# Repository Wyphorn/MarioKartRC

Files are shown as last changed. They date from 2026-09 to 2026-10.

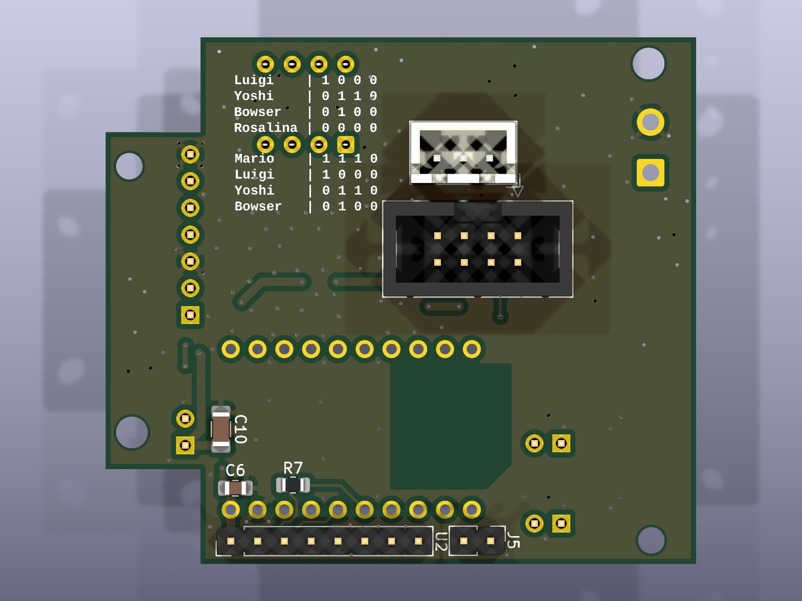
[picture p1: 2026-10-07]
docs/images/kart/3d_bottom.jpg

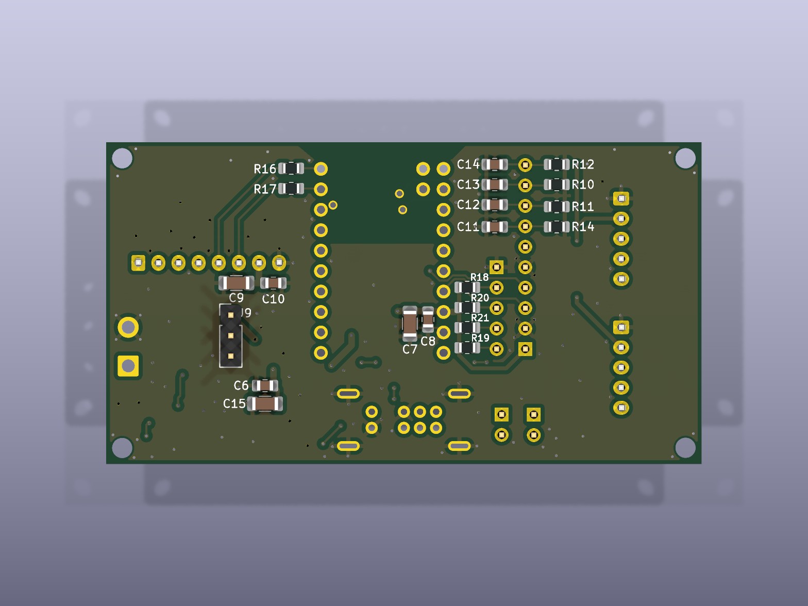
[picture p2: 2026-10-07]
docs/images/controller/3d_bottom.jpg

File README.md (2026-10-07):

# Mario Kart RC

Mario-Kart-inspiriertes RC-Rennsystem für 8 Fahrzeuge im Außeneinsatz. Die Autos fahren mit ~30 km/h; Items, Kollisionen und Rundenzählung werden automatisch erkannt.

Das Projekt ist auf Nachbau ausgelegt: Alle Bauteile haben eine feste Bestellnummer eines echten Herstellers mit öffentlichem Datenblatt und sind handlötbar (SOT-23, SOT-223, SMA, THT – kein QFN).

---

## Repo-Struktur

| Ordner | Inhalt |
|---|---|
| `fb-firmware/` | Fernbedienung – ESP32-C6-SuperMini, PlatformIO |
| `car-firmware/` | Fahrzeug – ESP32-C6 Mini, PlatformIO |
| `shared/` | Gemeinsamer Code: `mk_protocol.h` (Pakete FB ↔ Auto ↔ Basis), `mk_clock_guard.h` (Workaround für den C6-Uhrenfehler) |
| `kicad/projects/` | KiCad-Projekte je Platine: `kart` (Fahrzeug-Board), `controller` (Fernbedienung), `buttons` (Tasterplatine FB), `switch` (Schalter-Platinchen Kart), jeweils mit Gerber als ZIP |
| `kicad/libs/` | Eigene Symbole und Footprints (`zzzz_Own`, `RF_Module_Own`), von allen Projekten über ihre lokalen Bibliothekstabellen eingebunden |
| `kicad/archive/` | Alte Stände: FB-V1-Layout, erster FB-Schaltplan (D1 Mini, Mai 2026) |
| `docs/` | Weitere Dokumentation, u.a. `base-station.md` |

---

## Gesamtarchitektur

| Bereich | Technologie |
|---|---|
| Drahtlos | ESP-NOW |
| Kabelgebunden | CAN-Bus (STM32F103 + TJA1050) |
| Basisstation | Raspberry Pi 5 + USB-CAN-Adapter |
| Fahrzeugbasis | Carrera 2013 RC-Autos (umgebaut) |
| Fahrzeug-MCU | ESP32-C6 Mini |
| Fernbedienung | ESP32-C6-SuperMini (gleicher Chip wie im Auto) |

**Faustregel:** kabelgebunden = CAN, drahtlos = ESP-NOW.

---

## Betriebs-Modi

**Direct Mode** – Die Fernbedienung (FB) steuert ihr Auto direkt. Keine Basisstation nötig, ideal zum Einzelfahren und Testen.

**Game Mode** – Die FB spricht mit der Basisstation. Diese übernimmt die Spiellogik (Items, Punkte, Kollisionen, Rundenzählung) und leitet die Fahrbefehle ans Auto weiter.

Gewählt wird der Modus mit dem Schiebeschalter der FB: Mitte = Aus, Links = Game, Rechts = Direct.

---

## Kommunikationsprotokoll (`shared/mk_protocol.h`)

Alle ESP-NOW-Pakete beginnen mit einem `uint8_t type` als Unterscheidungsmerkmal.

| Struct | Richtung | Frequenz |
|---|---|---|
| `MK_ControlInput` | FB → Auto (Direct) / FB → Basis (Game) | ~50 Hz |
| `MK_ConfigPacket` | FB → Auto / FB → Basis → Auto | nur bei Änderung |
| `MK_GameFeedback` | Auto → FB (Direct) / Basis → FB (Game) | 5 Hz |
| `MK_Beacon` | FB/Auto → Broadcast | beim Pairing |
| `MK_Assign` | Basis → FB/Auto (Unicast) | beim Pairing |
| `MK_ChannelSwitch` | Basis/FB → Auto | Kanalwechsel / Rennende |
| `MK_Mapping` | Basis → FB/Auto (Unicast) | vor Rennstart |
| `MK_IrConfig` | Basis → Auto (Unicast) | nach Assign (nur Game Mode) |

- **`MK_ControlInput`** – `throttle` und `steering` (–100..100), `buttons` (Bitmaske Gelb/Grün/Blau/Rot), `maxSpeed` (1–10)
- **`MK_ConfigPacket`** – Servo-Trim –10..10; `save = 1` speichert im Auto-EEPROM, `save = 0` ist eine Live-Vorschau
- **`MK_GameFeedback`** – Position, Runde, Item, Rumble, Akkustand des Autos (0–5) und sein aktueller Servo-Trim
- **`MK_Beacon`** – enthält beim Auto die Charakter-ID (1–8)

### Pairing und Wiederverbinden (Direct Mode)

1. Erstes Pairing auf dem Setup-Kanal 1: Das Auto sendet Beacons, die FB antwortet mit `MK_Assign` und schickt es per `MK_ChannelSwitch` auf einen zufälligen Betriebskanal (4, 6, 9 oder 11).
2. Beide speichern Kanal und Gegenstelle im EEPROM.
3. **Wiederverbinden ist FB-gesteuert:** Nach einem Neustart oder Funkabriss meldet sich die FB mit ihrer echten MAC auf dem gespeicherten Kanal beim gespeicherten Auto und sendet einfach Steuerpakete. Das Feedback des Autos bestätigt die Verbindung – kein Beacon, kein erneutes Assign.
4. Rückfall auf Kanal 1 erst, wenn die Gegenstelle wirklich weg ist: Auto nach 30 s Funkstille (5 s direkt nach dem Einschalten), FB nach 30 s (15 s nach dem Einschalten). Kanal 1 wird bewusst vermieden, weil dort die erste FB gewinnt und die Zuordnung FB ↔ Auto wechseln könnte.

---

## Fernbedienung

### Hardware

| Komponente | Details |
|---|---|
| MCU | ESP32-C6-SuperMini (MakerGO) |
| Joysticks | 2× PS2-Analog-Stick, direkt an 3.3V (kein Spannungsteiler) |
| ADC | ADS1115 als Breakout-Modul, I2C 0x48 (ADDR → GND) |
| Display | 1.9" IPS 170×320, ST7789, SPI |
| Buttons | 4× Taster (SNES-Raute) + 2× Stick-Taster (verdrahtet, ohne Funktion) |
| Status-LED | WS2812B, 330 Ω Serienwiderstand |
| Rumble | 2× ERM-Vibrationsmotor 28×12 mm, parallel an Zellspannung |
| Rumble-Treiber | 1× MMBT2222A + 1 kΩ Basis, 1× SS14 Freilaufdiode |
| Akku | 1× 18650, ungeschützt – zum Laden herausnehmen (externes Ladegerät) |
| Verpolschutz | P-MOSFET DMG2301L-7 (Ersatz: DMG2301LK-7), direkt hinter dem Akku |
| Spannungsregler | LDO MCP1826T-3302E/DC, fest 3.3V, 1 A |
| Power/Modus | Schiebeschalter 2P3T: Pol A schaltet SHDN des LDO, Pol B den Modus-Pin |
| Akku-Messung | Teiler 100k/100k + 100 nF an GPIO0 |
| Puffer | 220 µF Elko an der Akkuschiene (Rumble-Anlaufstrom) |

Alle Verbraucher außer dem Rumble laufen an einer einzigen 3.3V-Schiene.

> **Hinweis für Nachbauer:** Auf FB-Board V1 ist die Freilaufdiode D2 im Footprint verdreht. Den Kathodenring entgegen dem Siebdruck auf Pad 2 (+BATT) setzen – das ist die Seite mit Durchgang zu Pin 1 von J6/J7.

### Pinbelegung ESP32-C6-SuperMini

| GPIO | Funktion |
|---|---|
| GPIO0 | ADC – Akku-Messung |
| GPIO1 | Modus-Pin (Game = GND, Direct = 3.3V) |
| GPIO2 | Button Rot |
| GPIO3 | Button Blau |
| GPIO4 | Button Grün |
| GPIO5 | Display MOSI |
| GPIO6 | WS2812B DATA |
| GPIO7 | Display SCK |
| GPIO14 | Display Backlight (PWM) |
| GPIO15 | Display CS |
| GPIO17 | Rumble PWM |
| GPIO18 | Display DC |
| GPIO19 | I2C SDA (ADS1115) |
| GPIO20 | I2C SCL (ADS1115) |
| GPIO21 / 22 | Stick-Taster R / L (inneres Pad, reserviert) |
| GPIO23 | Button Gelb (inneres Pad, einzelner Draht) |

Tabu: GPIO8/9 (Strapping, Onboard-LED/BOOT), GPIO12/13 (USB zum Flashen und für den Serial-Monitor), GPIO16 (UART0 TX, wird vom Boot-ROM getrieben).

ADS1115-Kanäle: A0 = Links X, A1 = Links Y, A2 = Rechts Y, A3 = Rechts X (A2/A3 bewusst getauscht, damit sich die Leitungen nicht kreuzen).

### Tastenbelegung

```
        [Blau]
   [Grün]      [Rot]
        [Gelb]
```

| Taste | Im Menü | Beim Fahren |
|---|---|---|
| Grün | Bestätigen | – |
| Rot | Zurück / Abbrechen | Licht am Auto an/aus |
| Blau | – | Charakter-Sound |
| Gelb | – | – (frei) |
| Grün + Blau 3 s | – | Menü öffnen |
| Rot 10 s halten | – | Einstellungen zurücksetzen (Countdown ab 5 s) |
| Rot beim Einschalten | Einstellungen zurücksetzen | |

Standardbelegung der Sticks: links hoch/runter = Gas, rechts links/rechts = Lenkung (im Menü tauschbar).

### Status-LED

| Farbe | Bedeutung |
|---|---|
| Orange blinkend | sucht Auto bzw. Basis |
| Grün | verbunden |
| Orange | Akku unter 33 % |
| Rot blinkend | Akku unter 16 % |
| Pink | Menü offen |
| Gelb pulsierend / solid | Kalibrierung startet / läuft |

### Einstellungsmenü

| Menüpunkt | Gespeichert |
|---|---|
| Offset-Kalibrierung (Nullpunkt der Sticks) | FB |
| Min/Max-Kalibrierung (8 geführte Schritte) | FB |
| Servo-Trim (±10, Räder bewegen sich live mit, Grün speichert, Rot verwirft) | Auto |
| Max. Speed (1–10) | – |
| Sprache (DE/EN) | FB |
| Rumble an/aus | – |
| Joysticks tauschen | – |
| Debug (Achsen, Buttons, Spannung, Kanal, MAC) | – |
| Reset | – |

Vor der ersten Fahrt **Offset-Kalibrierung** machen – sonst liegt der Nullpunkt der Sticks daneben und das Auto kriecht los.

### Akku

- 0 % = 3.4V, 100 % = 4.2V. Unter ~3.35V fällt der LDO aus der Regelung und die Joystick-Werte wandern – deshalb gilt die Zelle schon bei 3.4V als leer.
- **Tiefentladeschutz:** Liegt die Zelle 30 s unter 3.3V, zeigt die FB „Akku leer – bitte ausschalten“ und geht in Deep Sleep. Nur Aus- und Einschalten holt sie zurück. Ein Restverbrauch von wenigen mA bleibt; bei längerer Lagerung die Zelle herausnehmen.
- Nach 60 s ohne Eingabe wird das Display gedimmt.

---

## Fahrzeug

### Hardware

| Komponente | Details |
|---|---|
| MCU | ESP32-C6 Mini |
| Motortreiber | BTS7960 H-Brücke (IBT-2), 43 A Peak |
| Antrieb | 380er Bürstenmotor, 7.4V, Stallstrom ~8 A |
| Lenkservo | Multiplex MS-12022 MG DIGI, PWM 1050–1950 µs (mechanischer Puffer) |
| Audio | DFPlayer Mini (UART) – Sounds aus einem Ordner pro Charakter |
| IMU | LSM6DS3, I2C 0x6A – Kollisionserkennung |
| LEDs | WS2812B-Kette: Status-LED + 8er-Kreis im Charakterkopf |
| Beleuchtung | Front weiß + Heck rot, Rückfahrlicht weiß |
| IR-Sender | 3× IR-LED 940 nm nach unten (Mitte, ±8 cm) – Typ noch offen |
| Charakter-ID | 4-fach DIP-Schalter + Widerstandsleiter an einem ADC-Pin |
| Akku | 2× 18650 in Serie (2S), ungeschützt – zum Laden herausnehmen |
| Stromversorgung | 7.4V direkt an den BTS7960, 5V über Buck AP63205WU (C6, DFPlayer, LEDs, Servo) |
| Akku-Messung | Teiler 100k/47k an GPIO4 |

### Pinbelegung ESP32-C6 Mini

| GPIO | Funktion |
|---|---|
| GPIO0 | I2C SCL (LSM6DS3) |
| GPIO1 | I2C SDA (LSM6DS3) |
| GPIO2 | ADC – Charakter-ID |
| GPIO3 | IR-LED (über MMBT2222) |
| GPIO4 | ADC – Akku-Messung |
| GPIO5 | BTS7960 RPWM (10k Pulldown) |
| GPIO6 | BTS7960 LPWM (10k Pulldown) |
| GPIO7 | Servo PWM |
| GPIO14 | Rückfahrlicht |
| GPIO15 | Front- + Rücklicht |
| GPIO18 | UART1 TX → DFPlayer RX |
| GPIO19 | UART1 RX ← DFPlayer TX |
| GPIO20 | WS2812B DATA |

BTS7960 R_EN/L_EN fest an 5V. GPIO8/9 bleiben frei (Strapping: dürfen beim Reset nicht auf LOW gezogen werden).

### Charakter-Identifikation (DIP-Schalter)

10 kΩ nach 3.3V, dazu vier Widerstände (4.7k / 10k / 20k / 51k), je per DIP-Schalter nach GND. Der kleinste Abstand zwischen zwei Charakteren beträgt 254 mV.

| Charakter | DIP [4.7k 10k 20k 51k] | Spannung | SD-Ordner |
|---|---|---|---|
| Mario | 1110 | 0.713V | 01 |
| Luigi | 1000 | 1.055V | 02 |
| Yoshi | 0110 | 1.320V | 03 |
| Bowser | 0100 | 1.650V | 04 |
| DK | 0011 | 1.946V | 05 |
| Peach | 0010 | 2.200V | 06 |
| Toad | 0001 | 2.759V | 07 |
| Rosalina | 0000 | 3.300V | 08 |

Wird der DIP-Schalter umgestellt, während das Auto nicht verbunden ist, spielt es zur Kontrolle den Erkennungssound des neuen Charakters.

### SD-Karte des DFPlayers

```
/01/  001.mp3, 002.mp3, …   ← Mario
/02/  …                     ← Luigi
…
/08/  …                     ← Rosalina
/09/  …                     ← Spiel-Sounds (Stern, Banane, …)
```

Welche Tracks fröhlich bzw. traurig sind, steht in den Arrays `kJoy_*` / `kSad_*` am Anfang von `car-firmware/src/main.cpp`.

### LEDs

| Index | Funktion |
|---|---|
| 0 | Status-LED |
| 1–8 | Charakter-Kreis (Regenbogen) |

| Status-LED | Bedeutung |
|---|---|
| Orange blinkend | sucht / Verbindung unterbrochen |
| Grün | verbunden |
| Gelb | Akku unter 3.3V/Zelle |
| Rot blinkend | Akku unter 3.2V/Zelle – Abschaltung steht bevor |

### Akku

**Tiefentladeschutz:** Liegt der Akku 30 s unter 6.4V (3.2V/Zelle), stoppt das Auto, spielt einen traurigen Sound und geht in Deep Sleep. Jede Messung zählt, auch unter Last; eine erholte Messung beim Gaswegnehmen setzt den Zähler zurück. So löst es im Rennen erst aus, wenn der Akku wirklich leer ist.

### Kollisionserkennung

LSM6DS3 im ±16g-Bereich. Bei einem Stoß über der Schwelle vibriert die gekoppelte FB 2 s lang, danach 3 s Pause. Die Schwelle steht zum Testen auf 1.5g und soll nach dem Fahrtest wieder auf ~6g.

---

## Firmware bauen und flashen

```bash
cd fb-firmware      # bzw. car-firmware
pio run -t upload
pio device monitor
```

`upload_port`/`monitor_port` in `platformio.ini` sind auf die Seriennummern der eigenen Boards festgelegt – für andere Boards anpassen oder entfernen. Geflasht wird über den eingebauten USB-Port des C6 (USB-Serial/JTAG).

Beide Firmwares nutzen eine OTA-taugliche Partitionstabelle (`default.csv`). Sie lässt sich nur per USB ändern, deshalb ist sie ab dem ersten Flash gesetzt.

### ESP32-C6 rev v0.2: Uhr springt zurück

Beim ESP32-C6 in Revision v0.2 fallen im Zeitgeber gelegentlich einzelne Bits aus, sobald Funk und ein I2C-Master gleichzeitig laufen – `millis()` springt dann um Sekunden bis Minuten zurück ([esp-idf #19036](https://github.com/espressif/esp-idf/issues/19036)). Die Firmware umgeht das mit `shared/mk_clock_guard.h`:

- `nowMs()` zählt über den FreeRTOS-Tick, der auf einem nicht betroffenen Zähler läuft. Im eigenen Code **immer `nowMs()` statt `millis()` verwenden.**
- Ein Guard-Task erkennt Rücksprünge und setzt die Systemuhr zurück auf Stand (Log-Zeile `[CLOCK]`).
- Der WLAN-Stromsparmodus ist abgeschaltet.

Die Revision zeigt `esptool.py chip_id` an.

---

## Streckeninfrastruktur und IR-System

| Komponente | Funktion |
|---|---|
| TSOP38238 | IR-Empfänger, 38 kHz, ±45° – in Toren und Bodenplatten |
| STM32F103 + TJA1050 | CAN-Controller + Transceiver in den Tor-Nodes |
| RPi 5 + USB-CAN | Basisstation / Spielserver |

**Weg eines Ereignisses:** Auto fährt über eine Bodenplatte → TSOP38238 erkennt die IR-ID → STM32 → CAN → RPi 5 → Spiellogik.

Pro Tor sitzen drei Empfänger (Mitte und ±8 cm) passend zu den drei IR-LEDs am Auto. Bei 30 km/h bleibt ein Erkennungsfenster von ~5 ms.

---

## Projektstatus

| Schritt | Status |
|---|---|
| Architektur, Komponentenwahl, Protokoll | ✅ |
| Auto-Firmware (ESP-NOW, Motor, Servo, LEDs, IMU, Sound, Akku-Schutz) | ✅ |
| FB-Firmware auf ESP32-C6 portiert (Display, Menü, ESP-NOW, Rumble, Akku-Schutz) | ✅ |
| Direct Mode Ende-zu-Ende (Pairing, Reconnect, Trim, Sound, Licht) | ✅ |
| KiCad: Kart-Board und FB-Board | ✅ |
| FB-Board V1 gefertigt und aufgebaut | ✅ |
| Race-Display (Charakter, Position, Runde, Item) | ⏳ |
| IR-LED auswählen, einbauen, 38-kHz-Modulation | ⏳ |
| Verpolschutz + Hauptschalter am Akkuhalter des Autos | ⏳ |
| FB-Board V2 (Diode gedreht, Basis-Pulldown, 0.5-mm²-Anschlüsse) | ⏳ |
| Gehäuse anpassen (Fusion 360) | ⏳ |
| Basisstation-Software (Raspberry Pi) | ⏳ |
| Game Mode Ende-zu-Ende | ⏳ |
| OTA-Update | ⏳ zurückgestellt bis nach den ersten Fahrten |

---

## Verworfene Optionen

| Option | Grund |
|---|---|
| UWB für Positionierung | zu komplex |
| MAX98357A (I2S) für den Sound im Auto | DFPlayer Mini ist einfacher |
| DRV8833 als Motortreiber | max. 1.5 A gegen 8 A Stallstrom |
| IRFZ44N / RFP30N06LE für den Rumble | nicht Logic-Level bzw. zu groß |
| Piezo-Buzzer in der FB | kein Sound in der FB |
| D1 Mini (ESP8266) für die FB | ersetzt durch ESP32-C6: ein Chip-Typ für Auto und FB, Hardware-SPI fürs Display, einheitliches OTA |
| OLED (SSD1306/SSD1309) in der FB | ungünstiges Seitenverhältnis; stattdessen 1.9" IPS |
| Battery Shield / Buck-Boost für die FB | LDO genügt, die Schiene muss nur unter 3.6V bleiben; Buck-Boost-ICs waren QFN oder zu schwach |
| AMS1117 / LD1117 als FB-Regler | 1.1–1.3V Dropout – an einer 18650 unbrauchbar |
| 2 Zellen in der FB | konstruktiv ausgeschlossen |
| VSMA1094750X02 als IR-Sender | ±75° passt nicht zu den ±45° des TSOP38238 |

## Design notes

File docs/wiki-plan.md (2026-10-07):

# Wiki-Plan – Arbeitsliste

Steuerdatei für den Aufbau des öffentlichen GitHub-Wikis. **Wird nach jedem Schritt aktualisiert.**
Ablauf: Claude erledigt einen Schritt → meldet sich → gemeinsame Durchsicht → GO für den nächsten.

Status: ✅ fertig · 🔄 in Arbeit / in Durchsicht · ⏳ offen · ⏸ wartet auf User

| # | Schritt | Status |
|---|---|---|
| 0 | Plan erstellen und vorstellen | ✅ |
| 1 | Repo vorbereiten (aufräumen, Lizenz, Prüfung vor Veröffentlichung) | ✅ |
| 2 | Repo öffentlich schalten, Wiki aktivieren, Wiki-Gerüst (Home, Sidebar, Footer) | ✅ |
| 3 | Bilder aus KiCad exportieren (Schaltpläne, Platinen, 3D-Renderings) | ✅ |
| 4 | Seite: Projektüberblick und Systemarchitektur (inkl. Protokoll) | ✅ |
| 4b | Seite: Spielmodi (Rennen + Items, Hunter, Ideen wie Capture the Flag) | ✅ |
| 5 | Seiten: Hardware Fernbedienung | ✅ |
| 6 | Seiten: Hardware Kart (Kart-Board + Schalter-Platinchen) | ✅ |
| 7 | Seite: Pannen und Lehren (geflickte Platine, falsche Diode, Durchgeher, …) | ✅ |
| 8 | Seite: Software Fernbedienung | ✅ |
| 9 | Seite: Software Kart (inkl. OTA, DFPlayer/SD-Karte) | ✅ |
| 10 | Seite: Strecke, IR-System, Basisstation (Planungsstand) | ✅ |
| 11 | Seite: Nachbauen (Stückliste, Bestellen, Flashen, Akku-Regeln) | ✅ |
| 12 | Fotos und Video einbinden | ⏸ User liefert |
| 13 | README kürzen und aufs Wiki verweisen | ⏳ |
| 14 | Optional: Blog / „Was letzte Woche geschah“ | ⏳ später |

---

## Grundsatzentscheidungen

- **Ort:** GitHub-Wiki (Repo `MarioKartRC.wiki.git`, lokal geklont nach `../MarioKartRC.wiki/`).
- **Bilder** liegen im Hauptrepo unter `docs/images/` und werden im Wiki per
  `https://raw.githubusercontent.com/Wyphorn/MarioKartRC/main/docs/images/...` eingebunden —
  so sind sie versioniert, und das Wiki-Repo bleibt klein.
- **Sprache:** Deutsch. (Englisch ggf. später.) **Leser duzen**, Autor schreibt in Ich-Form.
- **Wiki lokal:** `~/Dokumente/MarioKartRC.wiki/` (eigenes Git-Repo, Identität = noreply wie Hauptrepo).
- **Quelle der Inhalte:** `CLAUDE.md`, `README.md`, `shared/mk_protocol.h`, Firmware, KiCad-Dateien.
  Das Wiki *erklärt*, es kopiert nicht jede Zahl — Datenblattwerte nur, wo sie eine Entscheidung begründen.
- **Ton:** erzählend, ehrlich. Auf der Startseite und im Footer: Projekt entsteht mit KI (Claude),
  Einstieg ohne KiCad-Vorkenntnisse.
- **Versionen:** Jede Hardware-Seite trennt klar V1 (gebaut, mit Macken) und V2 (bestellt 2026-10-07).

## Geplante Wiki-Seiten

```
Home                         – kurz: was, warum, Status, KI-Hinweis
├─ Systemüberblick           – Architektur, Modi, Funkprotokoll
├─ Spielmodi                 – Rennen + Items, Hunter, weitere Ideen
├─ Hardware
│  ├─ Fernbedienung          – Stromversorgung, Verpolschutz, Rumble, Pins, V1→V2
│  ├─ Tasterplatine
│  ├─ Kart-Board             – C6, Buck, Motor, Servo, IMU, Charakter-ID
│  └─ Schalter-Platinchen    – Back-to-back-FETs, Puffer, Status-LED
├─ Software
│  ├─ Firmware Fernbedienung – Menü, Kalibrierung, Display, Akku
│  └─ Firmware Kart          – Fahren, Kollision, Sound, Licht, OTA
├─ Strecke & IR-System       – Planung
├─ Pannen & Lehren
├─ Nachbauen
└─ (Blog)
```

## Entscheidungen des Users (2026-10-07)

1. **Lizenz:** niemand soll damit Geld verdienen, Nachbau erlaubt → **CC BY-NC-SA 4.0** für alles (`LICENSE`).
2. PDFs/DOCX und alles Vorläufige → `.gitignore`. Dateisystem darf frei umsortiert werden.
3. **CLAUDE.md wird nicht veröffentlicht** (interne Gedanken) → aus Git entfernt, in `.gitignore`.
4. Commit-E-Mail: alle Commits nutzen `wyphorn@users.noreply.github.com`, nichts zu tun.
5. Fan-Projekt-Hinweis „nicht Nintendo“ → ja (steht schon in `LICENSE`, kommt auf die Startseite).
6. Wiki-Erstanlage: GitHub legt das Wiki-Repo erst nach der ersten Seite über die Weboberfläche an —
   Claude gibt den Link, User klickt. Sprache: Deutsch.

## Schritt 1 – erledigt

- Sicherheitskopie: `~/Dokumente/MarioKartRC_backup_2026-10-07`
- KiCad neu geordnet: `kicad/projects/{kart,controller,buttons,switch}`, `kicad/libs/`, `kicad/archive/`.
  Jedes Projekt hat eigene `sym-lib-table`/`fp-lib-table` → `${KIPRJMOD}/../../libs/…`.
  `einschalter` → `switch`, Titel „Mario Kart PCB Switch“ Rev. 1. Alter Tasterentwurf `docs/kart/buttons/` verworfen.
  ERC/DRC vor/nach Umzug identisch (Kart: `RF_Module_Own` wird jetzt sogar gefunden).
- AO4407A-Footprint: kaputter 3D-Pfad (`C16072.3dshapes`) → KiCad-Standardmodell SOIC-8.
- Unbenutzte Footprint-Entwürfe `SOT-223_5MC_MCH-L/-M` entfernt.
- Firmware `car`, `car_v2`, `fb`, `fb_v2` baut.

- Nach Durchsicht: AO4407A-3D-Modell gedreht (`rotate 0 0 -90`, per Render geprüft: Beinchen über Pads, Pin-1-Punkt auf Pad 1).
- CLAUDE.md per `git filter-branch` aus der gesamten Historie entfernt, force-gepusht (30 Commits, neue Hashes).
- Globale KiCad-Symboltabelle bereinigt (`zzzz_Own`, `RF_Module_Own`, `zz_own` raus; nur noch KiCad-Standard).

## Schritt 3 – Bilder

- Skript `kicad/export_images.sh [board…]` → `docs/images/<board>/`: `schematic.svg/.pdf`, `layer_top/bottom.png`,
  `3d_top/bottom/iso.jpg`. Boards: `kart`, `controller`, `buttons`, `switch` (aktuell) + `kart_v1`, `controller_v1`
  (aus Commit `6059d1e`, Rev. 0.9). Nach jeder Platinenänderung neu laufen lassen. Gesamt ~12 MB.
- Einbinden im Wiki: `https://raw.githubusercontent.com/Wyphorn/MarioKartRC/main/docs/images/<board>/<datei>`
- Fotos von V1 liefert der User später (Schritt 12).

## Merkposten für spätere Schritte

- **Startsound des Karts:** behoben 2026-10-07 (DFPlayer-Reset vor den Selbsttests, Lautstärke + Sound danach). Gebaut (car, car_v2), **noch nicht geflasht/getestet** → Kart per OTA (`car_ota`) aktualisieren und prüfen, ob der Erkennungssound beim Kaltstart wieder kommt.

- **Schalter-Platinchen V2 (Idee):** +BATT/MID/BATT_SW-Flächen unter Q1/Q2 auch auf B.Cu, mit Vias. Bestellte V1: Power-Flächen nur F.Cu, keine Vias (geprüft 2026-10-07). Nach Lieferung Fingertest an Q1 bei blockiertem Motor.

- **Firmware `fb_v2` passt noch nicht zum V2-Schaltplan** (bekannt, steht in Memory project_status). **Maßgeblich ist das Layout/der Schaltplan, der Code wird angepasst** (User 2026-10-07): Tasten 14/15/18/19,
  I²C SDA 2, Display DC 3 / CS 4 / BL 5 / SCK 6 / MOSI 7. Wiki dokumentiert den Schaltplan. Tastenfarben/Stickachsen erst am Gerät.
- Seite „Pannen und Lehren“ (Schritt 7) wird von Fernbedienung und Startseite schon verlinkt — Name beibehalten.

- **Startseite** später ggf. kürzen (User-Eindruck: etwas viel Info). Sidebar-Einträge „(folgt)“ beim Anlegen jeder Seite in echte Links umwandeln.

- **Sounds:** erledigt 2026-10-07 (Quelle Sounds Resource MK64, Soll-Belegung im Wiki, lokale `sounds/` kanonisch umgebaut). Offen beim User: SD-Karten neu bespielen; Sounds für Rosalina und „vom Panzer getroffen“ fehlen.
- *(alt)* **Sounds (Schritt 11):** Die MP3/WAV-Dateien stammen aus dem Internet und werden **nicht** im Repo gehostet.
  Liegen seit 2026-10-07 lokal in `sounds/` (SD-Layout 01–09, 46 MP3 + 2 WAV, `.gitignore`). `09/old_002.mp3` ist ein Überbleibsel.
  User sucht die Quelle, das Wiki verlinkt nur. Dazu eine **Mapping-Tabelle**: Quelldatei → Dateiname auf der SD-Karte →
  Ordner (pro Charakter). Bezug: Memory „SD-Ordner umbenennen“ und
  README-Abschnitt „SD-Karte des DFPlayers“.

## Log

- 2026-10-07: Plan erstellt. Vorab geprüft: Repo privat, Wiki aus, 28 Commits, keine Zugangsdaten
  in der Historie (`mk_secrets.h` nie committet), `kicad-cli` 10.0.6 vorhanden.
- 2026-10-07: Schritt 1 umgesetzt und mit User durchgesehen, Historie bereinigt, gepusht. Wartet auf GO für Schritt 2.
- 2026-10-07: Repo öffentlich, Wiki aktiviert, Beschreibung + Topics gesetzt. Gerüst (Home, _Sidebar, _Footer) als Entwurf im Scratchpad; Push sobald User die erste Wiki-Seite angelegt hat.
- 2026-10-07: Schritt 2 fertig. Wiki-Gerüst gepusht (Home, _Sidebar, _Footer). User: Startseite evtl. zu viel Info, vorerst so lassen. Leser duzen.
- 2026-10-07: Schritt 3 umgesetzt, Bilder + Skript gepusht, wartet auf Durchsicht.
- 2026-10-07: Schritt 3 abgenommen (Zoom/Anschnitt bleibt so, Renderings sind Beiwerk).
- 2026-10-07: Schritt 4: Seite „Systemüberblick“ (Bausteine, ESP-NOW, Modi mit Mermaid-Diagrammen, Koppeln, Pakettabelle, Jäger-Modus). Sidebar verlinkt.
- 2026-10-07: Neue Seite „Spielmodi“ (User-Wunsch): Items und Hunter aus dem Systemüberblick ausgelagert, Capture the Flag als Idee.
- 2026-10-07: Schritt 4/4b abgenommen. Schritt 5: Seiten „Fernbedienung“ (V2, mit V1-Problemtabelle) und „Tasterplatine“ online.
- 2026-10-07: Schritt 5 abgenommen.
- 2026-10-07: Schritt 6: Seiten „Kart-Board“ (V2, Chassis, Figurenwahl-Tabelle, V1-Problemtabelle) und „Schalter-Platinchen“ online.
- 2026-10-07: Schritt 6 abgenommen. Schritt 7: Seite „Pannen und Lehren“ online (14 Geschichten in 5 Gruppen, inkl. „Arbeiten mit KI“).
- 2026-10-07: Schritt 7 abgenommen (+ Tippfehler-Anekdote, + dünner Lötdraht). „ratiometrisch“ stammte von Claude.
- 2026-10-07: Schritt 8: Seite „Firmware Fernbedienung“ online (Ablauf, Bedienung, Menü, Kalibrierung, LED, Display, Akku, Sicherheit, Bauen). Hinweis: Code-Kommentar Z.132 „Offset beim Boot“ ist veraltet.
- 2026-10-07: Schritt 8 abgenommen. Bestätigt: Offset nur im Menü; Max. Speed/Rumble/Sticks tauschen gelten bewusst nur für die Session. Code-Kommentar korrigiert.
- 2026-10-07: Schritt 9: Seite „Firmware Kart“ online (Fahren, Tasten/Stern, SD-Layout, LEDs, Kollision, Akku, OTA-Anleitung, Envs, Offenes).
- 2026-10-07: Schritt 9 abgenommen. Startsound im Wiki gestrichen, Heimnetz durch Platzhalter ersetzt (Wiki + platformio.ini).
- 2026-10-07: Schritt 10: Seite „Strecke und IR-System“ online. Geklärt: −8/0/+8 cm = Sender am Auto, Empfänger im 5-cm-Raster (Vernier: max. 1 cm Abstand).
- 2026-10-07: Schritt 11: Seite „Nachbauen“ online, Stücklisten-CSV unter docs/bom/ (Export im Skript). Offen: Sound-Quelle (User), Stand der Ordner in sounds/ (alt/kanonisch?), 09/003–006 Inhalt; 07=08 identisch, 03/04 nur je 2 verschiedene Dateien.
- 2026-10-07: Sound-Abschnitt fertig. sounds/ umgebaut (02 Luigi, 03 Yoshi, 04 Bowser, 05 DK), 09/002 = Original wiederhergestellt.
- 2026-10-07: Schritt 11 abgenommen (Links zu allen Kaufteilen ergänzt).

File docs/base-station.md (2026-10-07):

# Basisstation – Architektur

## Überblick

Die Basisstation besteht aus einem Raspberry Pi 5 und vier ESP32-S3-Modulen, alle
per USB verbunden. Drei S3s sind aktiv, einer ist Standby.

```
                    RPi 5
                   /  |  \ \
            USB   /   |   \ \
                 /    |    \ \
              S3-1  S3-2  S3-3  S3-4(Standby)
              CH1   CH6   CH11
```

## ESP32-S3 als Relay

Jeder aktive S3:
- Spooft seine MAC auf `MK_BASE_MAC` (DEADBEEF:BA5E) beim Start
- Operiert auf einem dedizierten, nicht-überlappenden Kanal
- Verwaltet die ihm zugewiesenen FB+Auto-Paare
- Empfängt `MK_ControlInput` von der FB, wendet Spieleffekte an, leitet
  das modifizierte Paket ans Auto weiter
- Empfängt Spielzustands-Updates vom RPi per USB Serial

### Kanalverteilung

| S3 | Kanal | Nicht-überlappend |
|---|---|---|
| S3-1 | 1 | ✓ |
| S3-2 | 6 | ✓ |
| S3-3 | 11 | ✓ |

Kanalwahl CH1/6/11 entspricht den drei nicht-überlappenden 2.4GHz-Kanälen.
Bis zu 8 Fahrzeuge werden gleichmäßig auf die drei S3s aufgeteilt (~2–3 pro S3).

### Input-Modifikation (Spieleffekte)

Der S3 sitzt als transparenter Mittelsmann zwischen FB und Auto.
FB- und Auto-Firmware bleiben unverändert.

```
FB  →  MK_ControlInput (original)  →  S3  →  MK_ControlInput (modifiziert)  →  Auto
```

Mögliche Modifikationen (per `S3_GameState` vom RPi konfiguriert):
- `speedFactor`: additiver Throttle-Offset (-100..100), für Bonus/Malus
- `invertSteering`: Lenkung invertieren (Bananenschale, etc.)
- `maxSpeedOverride`: maximale Geschwindigkeit überschreiben (1–10, 0 = Spieler-Wert)

## Failover

Der RPi erkennt den Ausfall eines S3 **sofort** über den USB-Disconnect-Event –
kein Heartbeat-Timeout nötig.

Failover-Ablauf:
1. RPi erkennt USB-Disconnect von S3-x
2. RPi sendet Konfiguration des ausgefallenen S3 an S3-4 (Standby):
   - Kanal
   - Zugewiesene Fahrzeuge (MAC, Slot, Spielzustand)
3. S3-4 spooft dieselbe MAC (`MK_BASE_MAC`) auf demselben Kanal
4. Autos und FBs bemerken nichts – gleiche MAC, gleicher Kanal

Hinweis: `S3_Heartbeat` (alle 500ms) ergänzt den USB-Disconnect für den Fall
dass ein S3 zwar verbunden aber eingefroren ist (Firmware-Hang ohne Reboot).

## USB Serial Protokoll (RPi ↔ S3)

Binäres Protokoll über USB CDC. Jede Nachricht beginnt mit einem `uint8_t`-Typ.
Framing: Länge wird durch den bekannten Struct-Typ impliziert (kein Length-Byte).

Siehe `shared/mk_protocol.h` für Struct-Definitionen (`S3_*`).

### RPi → S3

| Typ | Wann |
|---|---|
| `S3_ASSIGN` | Nach Pairing eines FB+Auto-Paares |
| `S3_GAMESTATE`| Bei Spielereignis (Item, Kollision, Runde...) |

### S3 → RPi

| Typ | Wann |
|---|---|
| `S3_STATUS` | Jedes Mal wenn Auto-Feedback eintrifft (5Hz) |
| `S3_HEARTBEAT`| Alle 500ms |

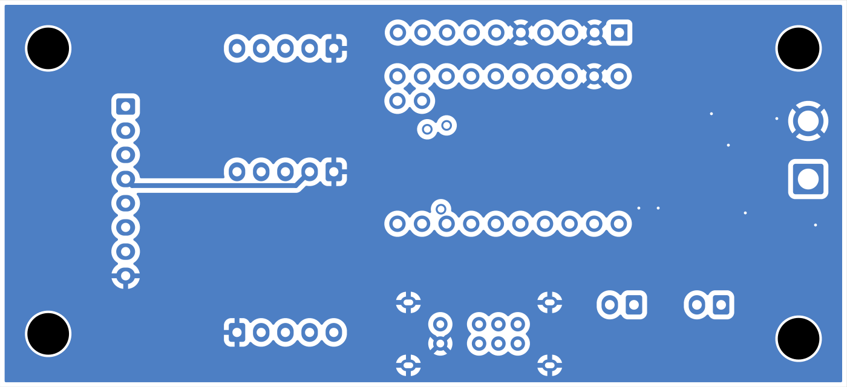
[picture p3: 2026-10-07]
docs/images/controller_v1/layer_bottom.png

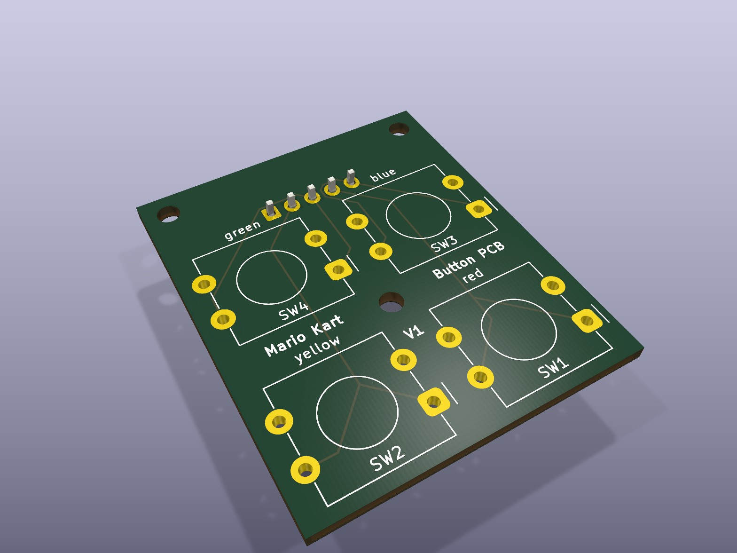
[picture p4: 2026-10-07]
docs/images/buttons/3d_iso.jpg

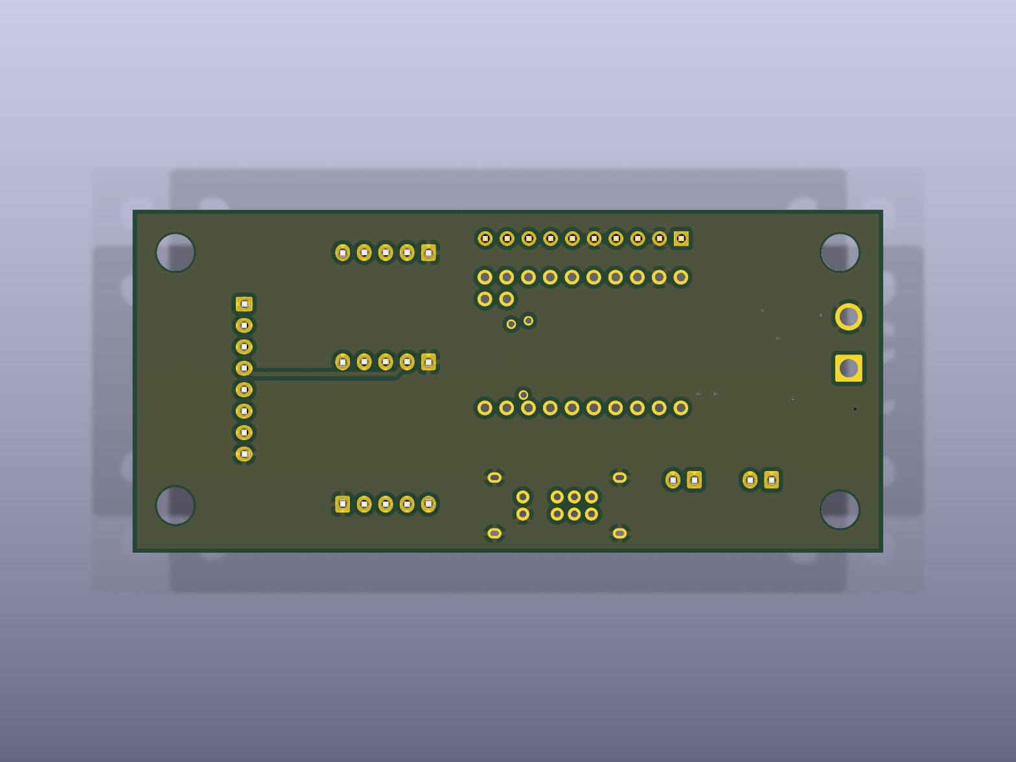
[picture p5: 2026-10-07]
docs/images/controller_v1/3d_bottom.jpg

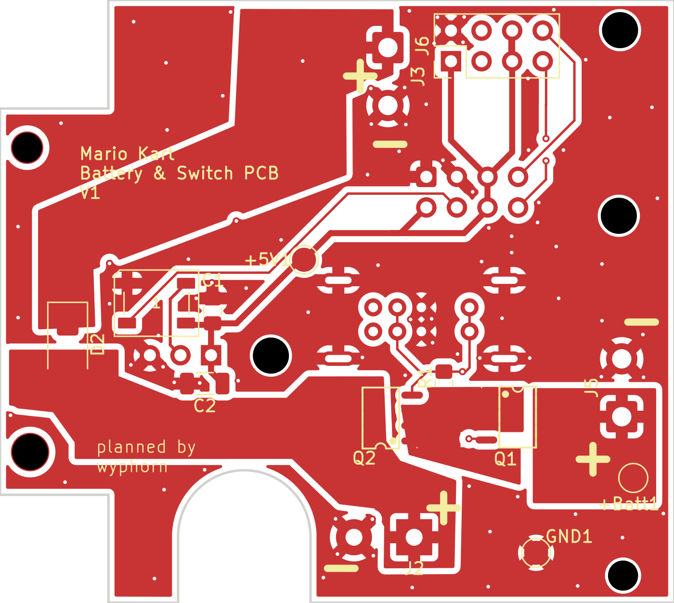
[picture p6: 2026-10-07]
docs/images/switch/layer_top.png

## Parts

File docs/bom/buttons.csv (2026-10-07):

Referenz | Wert | Footprint | Anzahl | Bestellnummer | Hersteller
J1 | Conn_01x05_Pin | Connector_JST:JST_XH_S5B-XH-A-1_1x05_P2.50mm_Horizontal | 1
SW1 | red | zzzz_Own:SW_Tactile_12x12mm_THT_P12.5x5.0mm | 1
SW2 | yellow | zzzz_Own:SW_Tactile_12x12mm_THT_P12.5x5.0mm | 1
SW3 | blue | zzzz_Own:SW_Tactile_12x12mm_THT_P12.5x5.0mm | 1
SW4 | green | zzzz_Own:SW_Tactile_12x12mm_THT_P12.5x5.0mm | 1

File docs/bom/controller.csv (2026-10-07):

Referenz | Wert | Footprint | Anzahl | Bestellnummer | Hersteller
C1 | 4,7µF | Capacitor_SMD:C_0805_2012Metric_Pad1.18x1.45mm_HandSolder | 1
C2 | 1µF | Capacitor_SMD:C_0805_2012Metric_Pad1.18x1.45mm_HandSolder | 1
C3 | 220µF | Capacitor_SMD:CP_Elec_6.3x5.4 | 1
C4-C6,C8,C10-C14 | 100nF | Capacitor_SMD:C_0805_2012Metric_Pad1.18x1.45mm_HandSolder | 9
C7,C9,C15 | 10µF | Capacitor_SMD:C_1206_3216Metric_Pad1.33x1.80mm_HandSolder | 3
D1 | WS2812B | LED_SMD:LED_WS2812B_PLCC4_5.0x5.0mm_P3.2mm | 1
D2 | D_Schottky | Diode_SMD:D_SMA_Handsoldering | 1
J1 | Buttons | Connector_PinHeader_2.54mm:PinHeader_1x05_P2.54mm_Vertical | 1
J2 | Joystick left | Connector_JST:JST_XH_S5B-XH-A-1_1x05_P2.50mm_Horizontal | 1
J3 | Joystick right | Connector_JST:JST_XH_S5B-XH-A-1_1x05_P2.50mm_Horizontal | 1
J4 | Display | Connector_JST:JST_XH_S8B-XH-A-1_1x08_P2.50mm_Horizontal | 1
J5 | 18650 | Connector_Wire:SolderWire-0.75sqmm_1x02_P4.8mm_D1.25mm_OD2.3mm | 1
J6 | Rumble1 | Connector_PinHeader_2.54mm:PinHeader_1x02_P2.54mm_Vertical | 1
J7 | Rumble2 | Connector_PinHeader_2.54mm:PinHeader_1x02_P2.54mm_Vertical | 1
J8 | ADS1115 | Connector_PinHeader_2.54mm:PinHeader_1x10_P2.54mm_Vertical | 1
J9 | LEDs | Connector_PinHeader_2.54mm:PinHeader_1x03_P2.54mm_Vertical | 1
Q1,Q3 | DMG2301L | Package_TO_SOT_SMD:SOT-23_Handsoldering | 2
Q2 | MMBT2222A | Package_TO_SOT_SMD:SOT-23_Handsoldering | 1
R1,R4,R5 | 100k | Resistor_SMD:R_0805_2012Metric_Pad1.20x1.40mm_HandSolder | 3
R3 | 1k | Resistor_SMD:R_0805_2012Metric_Pad1.20x1.40mm_HandSolder | 1
R6 | 330 | Resistor_SMD:R_0805_2012Metric_Pad1.20x1.40mm_HandSolder | 1
R7,R18-R21 | 10k | Resistor_SMD:R_0805_2012Metric_Pad1.20x1.40mm_HandSolder | 5
R8-R15 | 1MΩ | Resistor_SMD:R_0805_2012Metric_Pad1.20x1.40mm_HandSolder | 8
R16,R17 | 33Ω | Resistor_SMD:R_0805_2012Metric_Pad1.20x1.40mm_HandSolder | 2
SW2 | SW_DP3T | zzzz_Own:SW_Slide_2P3T_8pin_P2.0mm_MountingLugs | 1
U2 | ESP32-C6-SUPERMINI | zzzz_Own:ESP32-C6-SuperMini_2x10_P2.54mm_Row15.24mm | 1
U3 | MCP1826T-3302E/DC | zzzz_Own:SOT-223_5MC_MCH | 1

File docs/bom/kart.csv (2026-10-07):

Referenz | Wert | Footprint | Anzahl | Bestellnummer | Hersteller
+3V3 | +3V3 | TestPoint:TestPoint_Pad_D2.0mm | 1
+5V1 | +5V | TestPoint:TestPoint_Pad_D2.0mm | 1
+Batt1 | +Batt | TestPoint:TestPoint_Pad_D2.0mm | 1
C1 | 10µF | Capacitor_SMD:C_1206_3216Metric_Pad1.33x1.80mm_HandSolder | 1
C2 | 22µF | Capacitor_SMD:C_1206_3216Metric_Pad1.33x1.80mm_HandSolder | 1
C3,C6,C7,C9 | 100nF | Capacitor_SMD:C_0805_2012Metric_Pad1.18x1.45mm_HandSolder | 4
C5 | 220uF | Capacitor_SMD:CP_Elec_6.3x5.4 | 1
C8,C10 | 22uF | Capacitor_SMD:C_1206_3216Metric_Pad1.33x1.80mm_HandSolder | 2
GND1 | GND | TestPoint:TestPoint_Pad_D2.0mm | 1
J2 | Servo | Connector_JST:JST_XH_B3B-XH-A_1x03_P2.50mm_Vertical | 1
J3 | Motor_Driver | Connector_IDC:IDC-Header_2x04_P2.54mm_Vertical | 1
J4 | 2S Lipo | Connector_Wire:SolderWire-0.75sqmm_1x02_P4.8mm_D1.25mm_OD2.3mm | 1
J5 | Speaker | Connector_PinHeader_2.54mm:PinHeader_1x02_P2.54mm_Vertical | 1
J7 | IR LEDs | Connector_PinHeader_2.54mm:PinHeader_1x02_P2.54mm_Vertical | 1
J8 | Beleuchtung | Connector_PinHeader_2.54mm:PinHeader_1x02_P2.54mm_Vertical | 1
J9 | Rückwärts | Connector_PinHeader_2.54mm:PinHeader_1x02_P2.54mm_Vertical | 1
L1 | 4.7µH | Inductor_SMD:L_Bourns_SRN6045TA | 1
Q1 | MMBT2222A | Package_TO_SOT_SMD:SOT-23_Handsoldering | 1
Q2,Q3 | Beleuchtung | Package_TO_SOT_SMD:SOT-23_Handsoldering | 2
R1-R3 | 1K | Resistor_SMD:R_0805_2012Metric_Pad1.20x1.40mm_HandSolder | 3
R4-R6,R9-R12 | 10k | Resistor_SMD:R_0805_2012Metric_Pad1.20x1.40mm_HandSolder | 7
R7 | 1k | Resistor_SMD:R_0805_2012Metric_Pad1.20x1.40mm_HandSolder | 1
R8 | 4.7k | Resistor_SMD:R_0805_2012Metric_Pad1.20x1.40mm_HandSolder | 1
R13 | 20k | Resistor_SMD:R_0805_2012Metric_Pad1.20x1.40mm_HandSolder | 1
R14 | 47k | Resistor_SMD:R_0805_2012Metric_Pad1.20x1.40mm_HandSolder | 1
R15 | 51k | Resistor_SMD:R_0805_2012Metric_Pad1.20x1.40mm_HandSolder | 1
R16 | 100k | Resistor_SMD:R_0805_2012Metric_Pad1.20x1.40mm_HandSolder | 1
R17 | 330 | Resistor_SMD:R_0805_2012Metric_Pad1.20x1.40mm_HandSolder | 1
SW1 | Characterwähler | Button_Switch_THT:SW_DIP_SPSTx04_Piano_10.8x11.72mm_W7.62mm_P2.54mm | 1
U1 | ESP32-C6-SUPERMINI | zzzz_Own:ESP32-C6-SuperMini_2x10_P2.54mm_Row15.24mm | 1
U2 | DFPlayer Mini | Connector_PinHeader_2.54mm:PinHeader_1x08_P2.54mm_Vertical | 1
U3 | LSM6DS3 | Connector_PinHeader_2.54mm:PinHeader_1x07_P2.54mm_Vertical | 1
U6 | AP63205WU | Package_TO_SOT_SMD:TSOT-23-6 | 1

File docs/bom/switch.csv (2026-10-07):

Referenz | Wert | Footprint | Anzahl | Bestellnummer | Hersteller
+5V1 | +5V | TestPoint:TestPoint_Pad_D2.0mm | 1
+Batt1 | +Batt | TestPoint:TestPoint_Pad_D2.0mm | 1
C1 | 100nF | Capacitor_SMD:C_0805_2012Metric_Pad1.18x1.45mm_HandSolder | 1
C2 | 22 µF | Capacitor_SMD:C_1206_3216Metric | 1
C3 | C_Polarized | zzzz_Own:CP_Elec_12.5x13.5 | 1
D1 | WS2812B | LED_SMD:LED_WS2812B_PLCC4_5.0x5.0mm_P3.2mm | 1
D2 | SS34 | Diode_SMD:D_SMA | 1
GND1 | GND | TestPoint:TestPoint_Pad_D2.0mm | 1
J1 | Motor_Driver | Connector_IDC:IDC-Header_2x04_P2.54mm_Vertical | 1
J2 | BTS | zzzz_Own:Pins_1x02_P5.0mm_D1.4mm_OD3.0mm | 1
J3 | KartCon | Connector_Wire:SolderWire-0.75sqmm_1x02_P4.8mm_D1.25mm_OD2.3mm | 1
J4 | WS2812b | Connector_PinHeader_2.54mm:PinHeader_1x03_P2.54mm_Vertical | 1
J5 | 2S Lipo | Connector_Wire:SolderWire-0.75sqmm_1x02_P4.8mm_D1.25mm_OD2.3mm | 1
J6 | Motor_Driver | Connector_PinHeader_2.54mm:PinHeader_2x04_P2.54mm_Vertical | 1
Q1,Q2 | AO4407A | zzzz_Own:SOIC-8_L4.9-W3.9-P1.27-LS6.0-BL | 2 | AO4407A | AOS
R1 | 100k | Resistor_SMD:R_0805_2012Metric_Pad1.20x1.40mm_HandSolder | 1
SW1 | SW_DP3T | zzzz_Own:SW_Slide_2P3T_8pin_P2.0mm_MountingLugs | 1

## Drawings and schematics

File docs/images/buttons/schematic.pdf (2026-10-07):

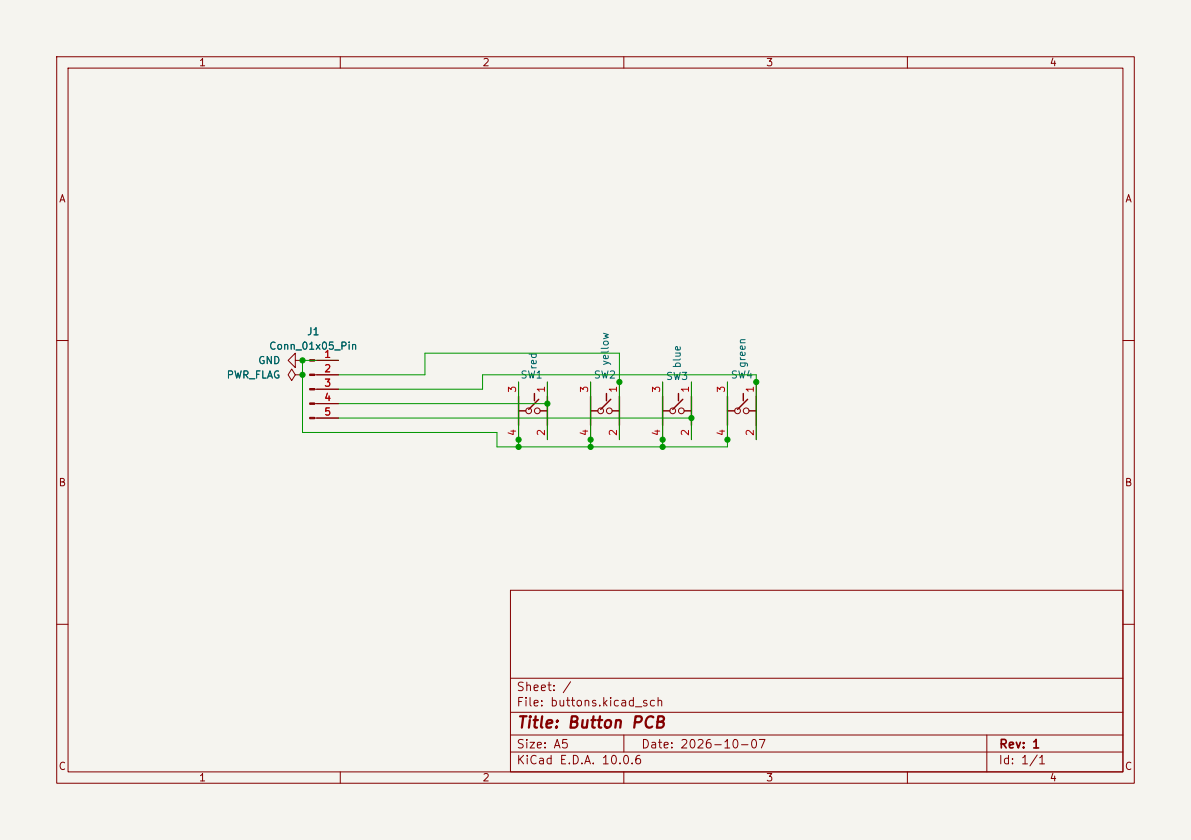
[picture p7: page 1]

Size: A5 | Rev: 1 | C Date: 2026-10-07
KiCad E.D.A. 10.0.6 | Id: 1/1

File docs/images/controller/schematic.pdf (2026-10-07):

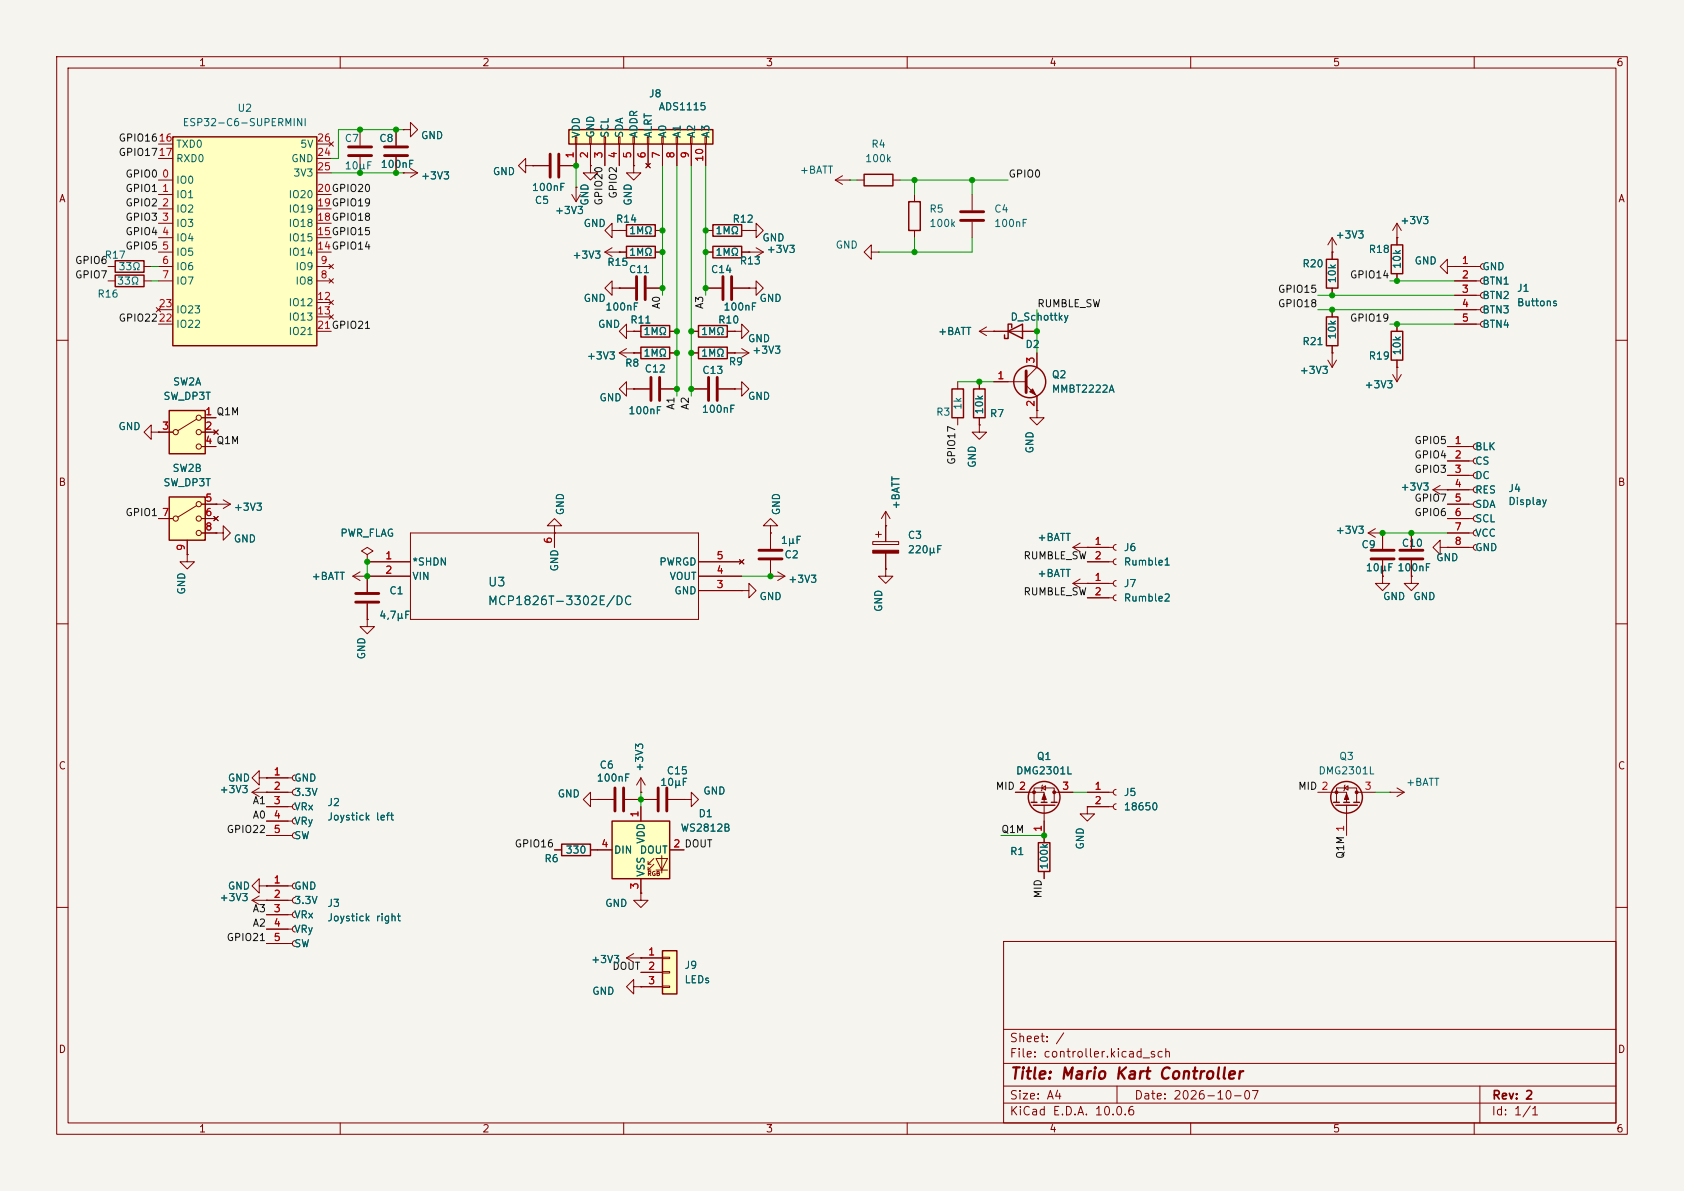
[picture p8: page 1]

J4Display BLK 1 CS 2 DC 3 RES 4

Sheet: /
File: controller.kicad_sch
Title: Mario Kart Controller

Size: A4 | Rev: 2
KiCad E.D.A. 10.0.6 | Id: 1/1

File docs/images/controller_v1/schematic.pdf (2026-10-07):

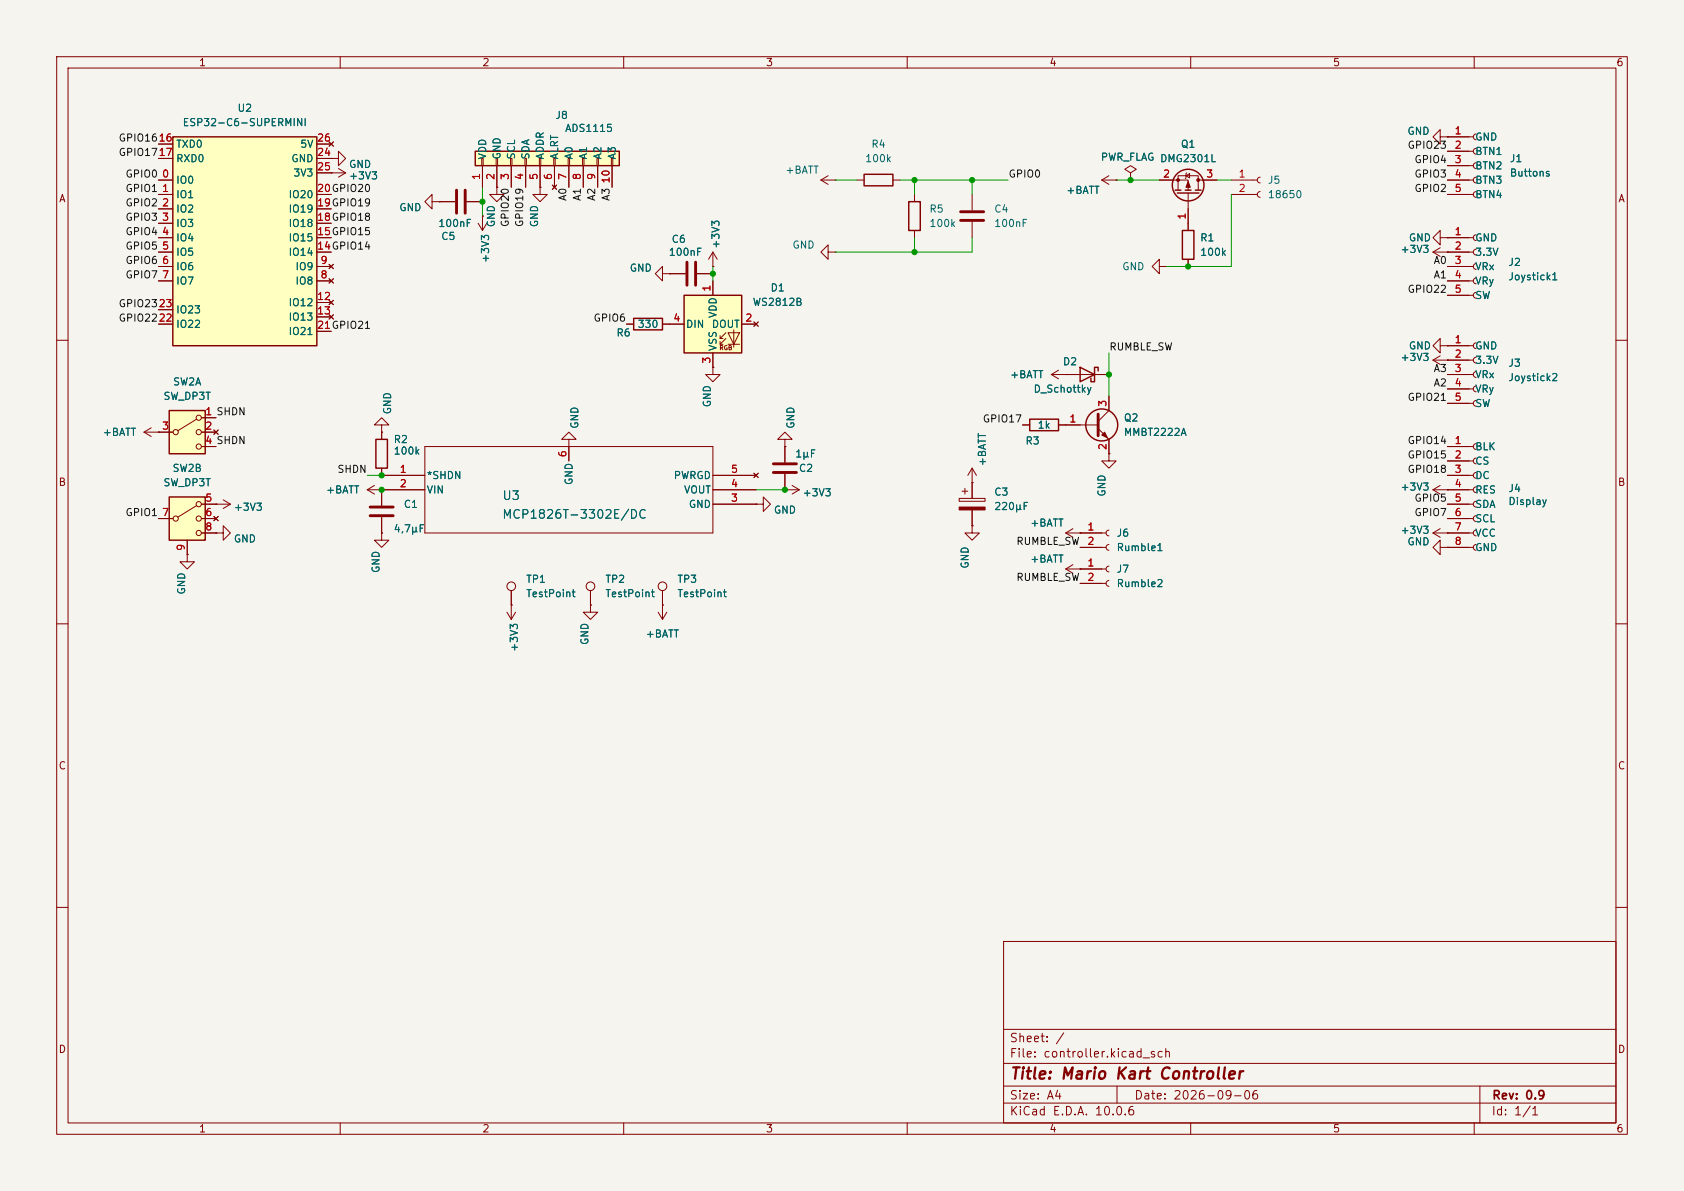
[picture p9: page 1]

J4Display BLK 1 CS 2 DC 3 RES 4

Sheet: /
File: controller.kicad_sch
Title: Mario Kart Controller

Size: A4 | Rev: 0.9
KiCad E.D.A. 10.0.6 | Id: 1/1

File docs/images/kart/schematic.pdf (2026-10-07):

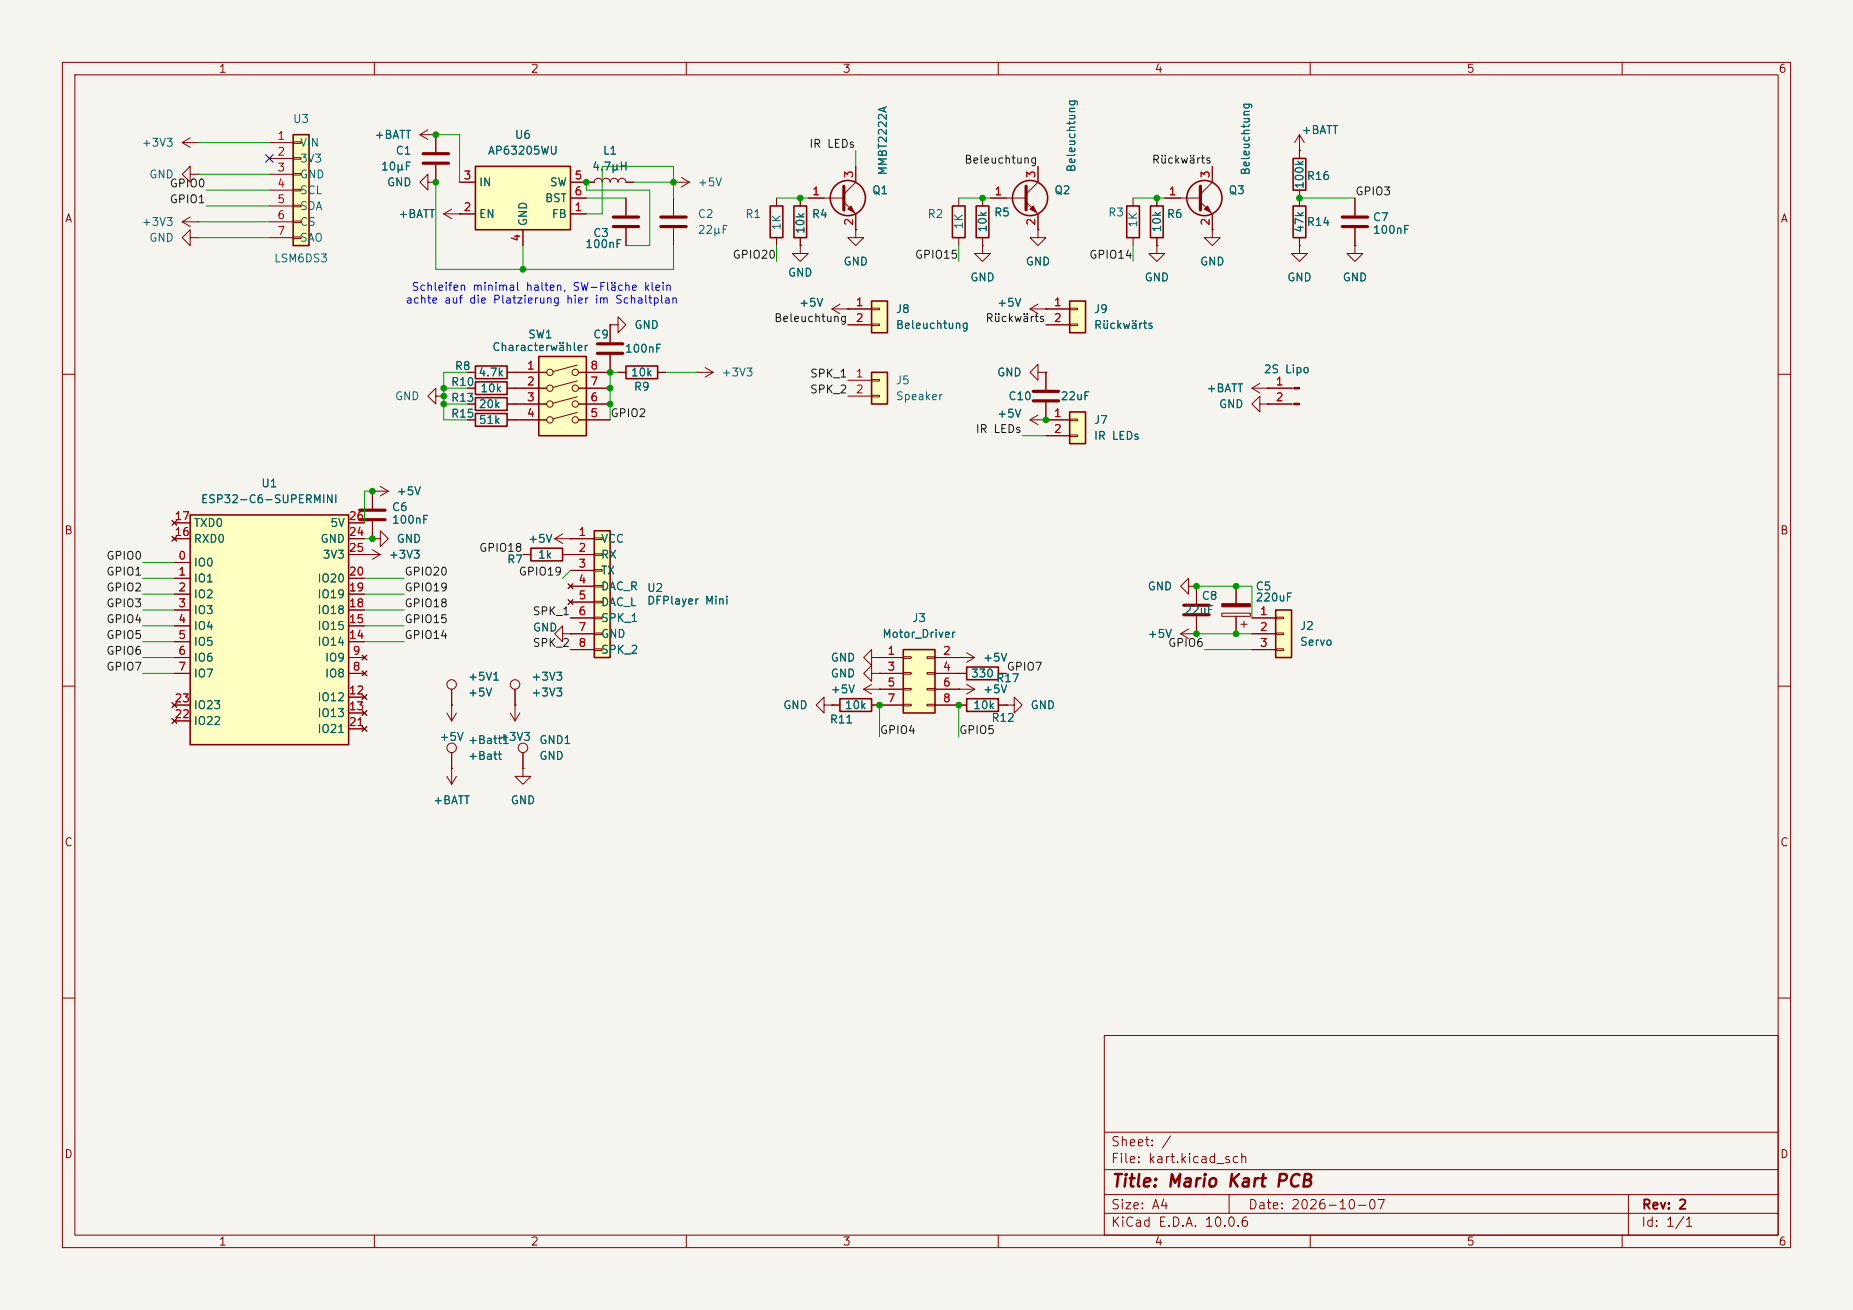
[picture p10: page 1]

Schleifen minimal halten, SW-Fläche klein

Sheet: /
File: kart.kicad_sch
Title: Mario Kart PCB

Size: A4 | Rev: 2
KiCad E.D.A. 10.0.6 | Id: 1/1

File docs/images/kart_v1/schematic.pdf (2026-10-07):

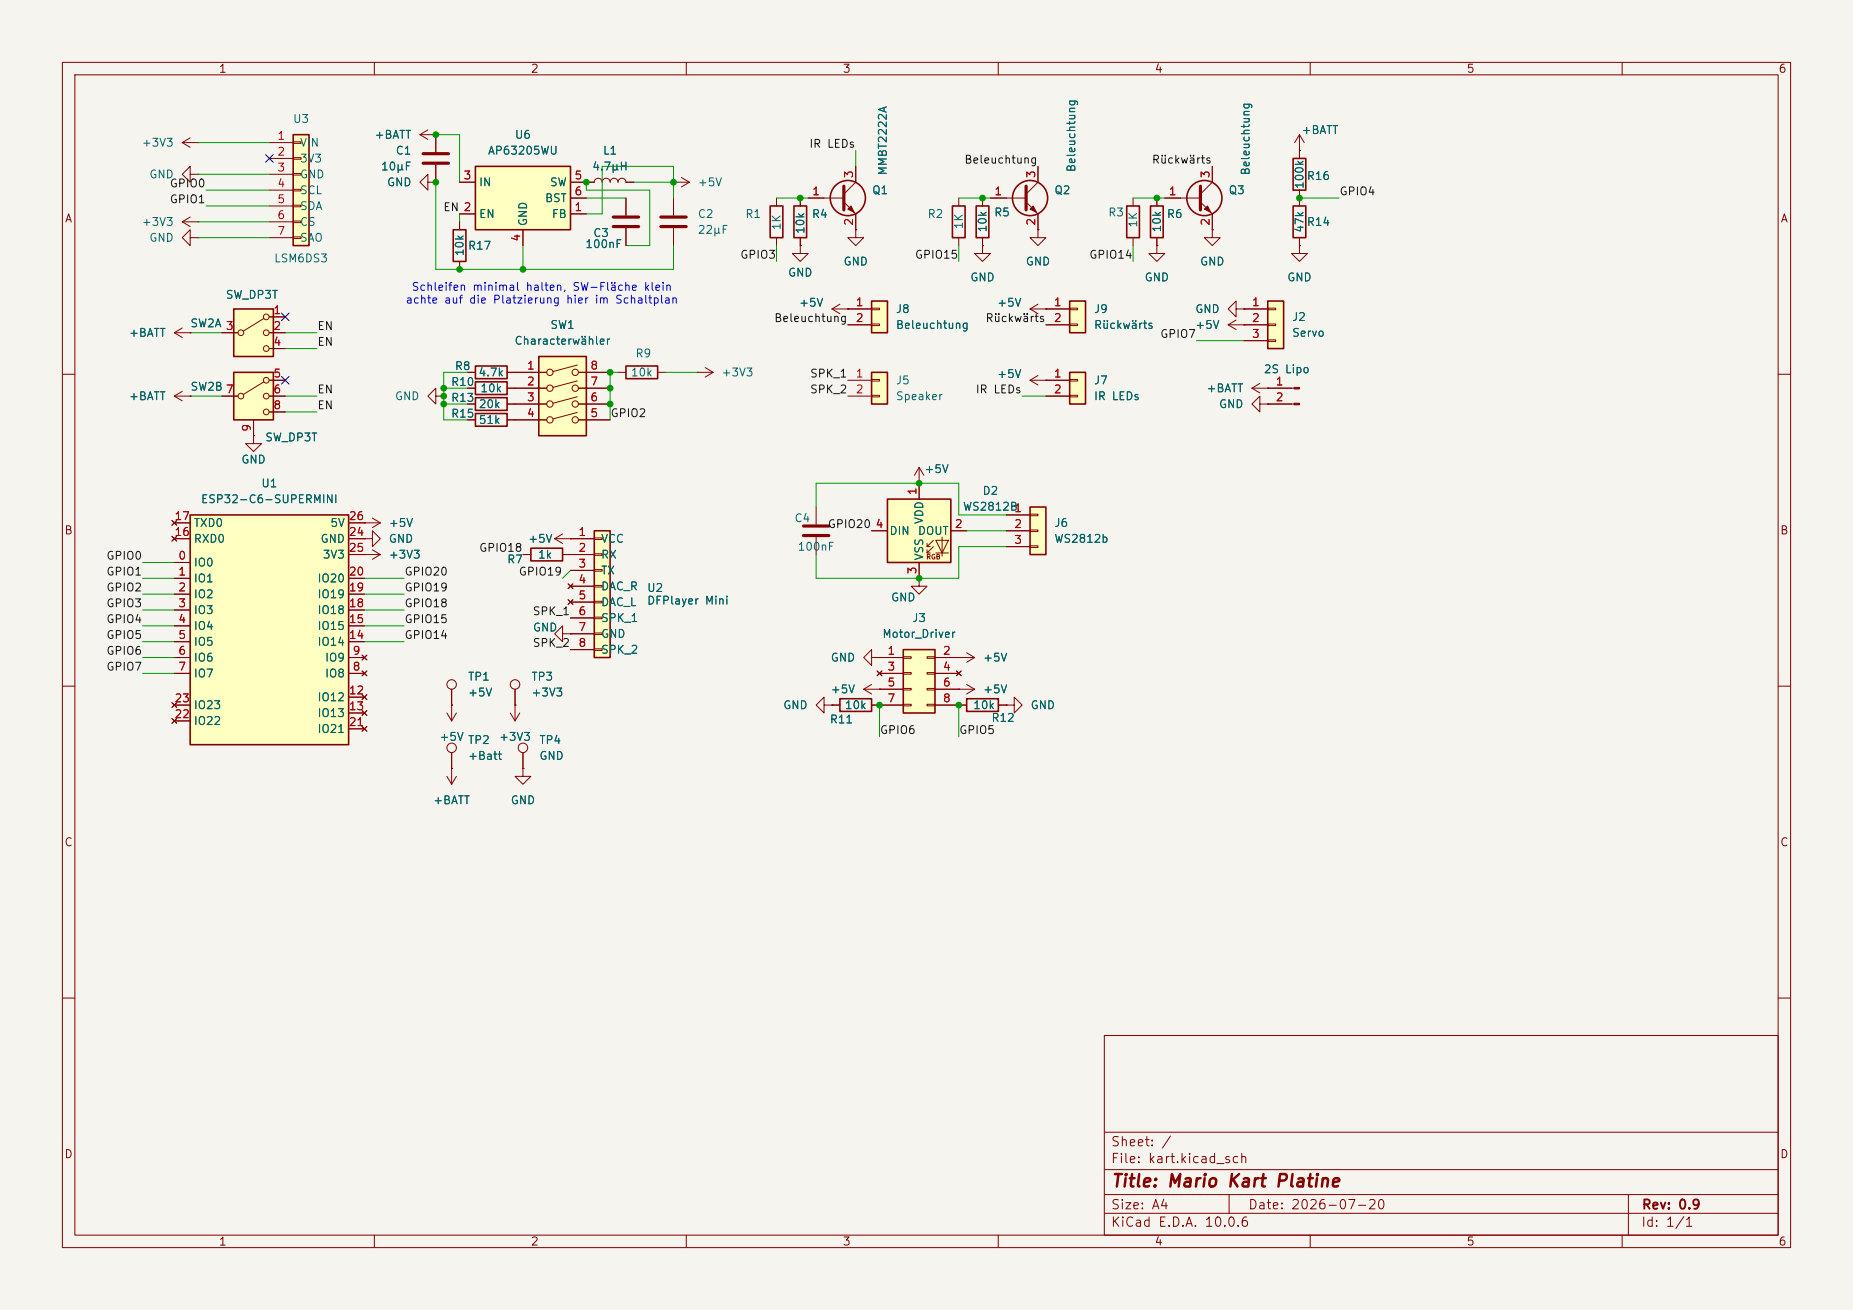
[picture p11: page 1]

achte auf die Platzierung hier im Schaltplan C3

Schleifen minimal halten, SW-Fläche klein

File: kart.kicad_sch
Title: Mario Kart Platine

Size: A4 | Rev: 0.9
KiCad E.D.A. 10.0.6 | Id: 1/1

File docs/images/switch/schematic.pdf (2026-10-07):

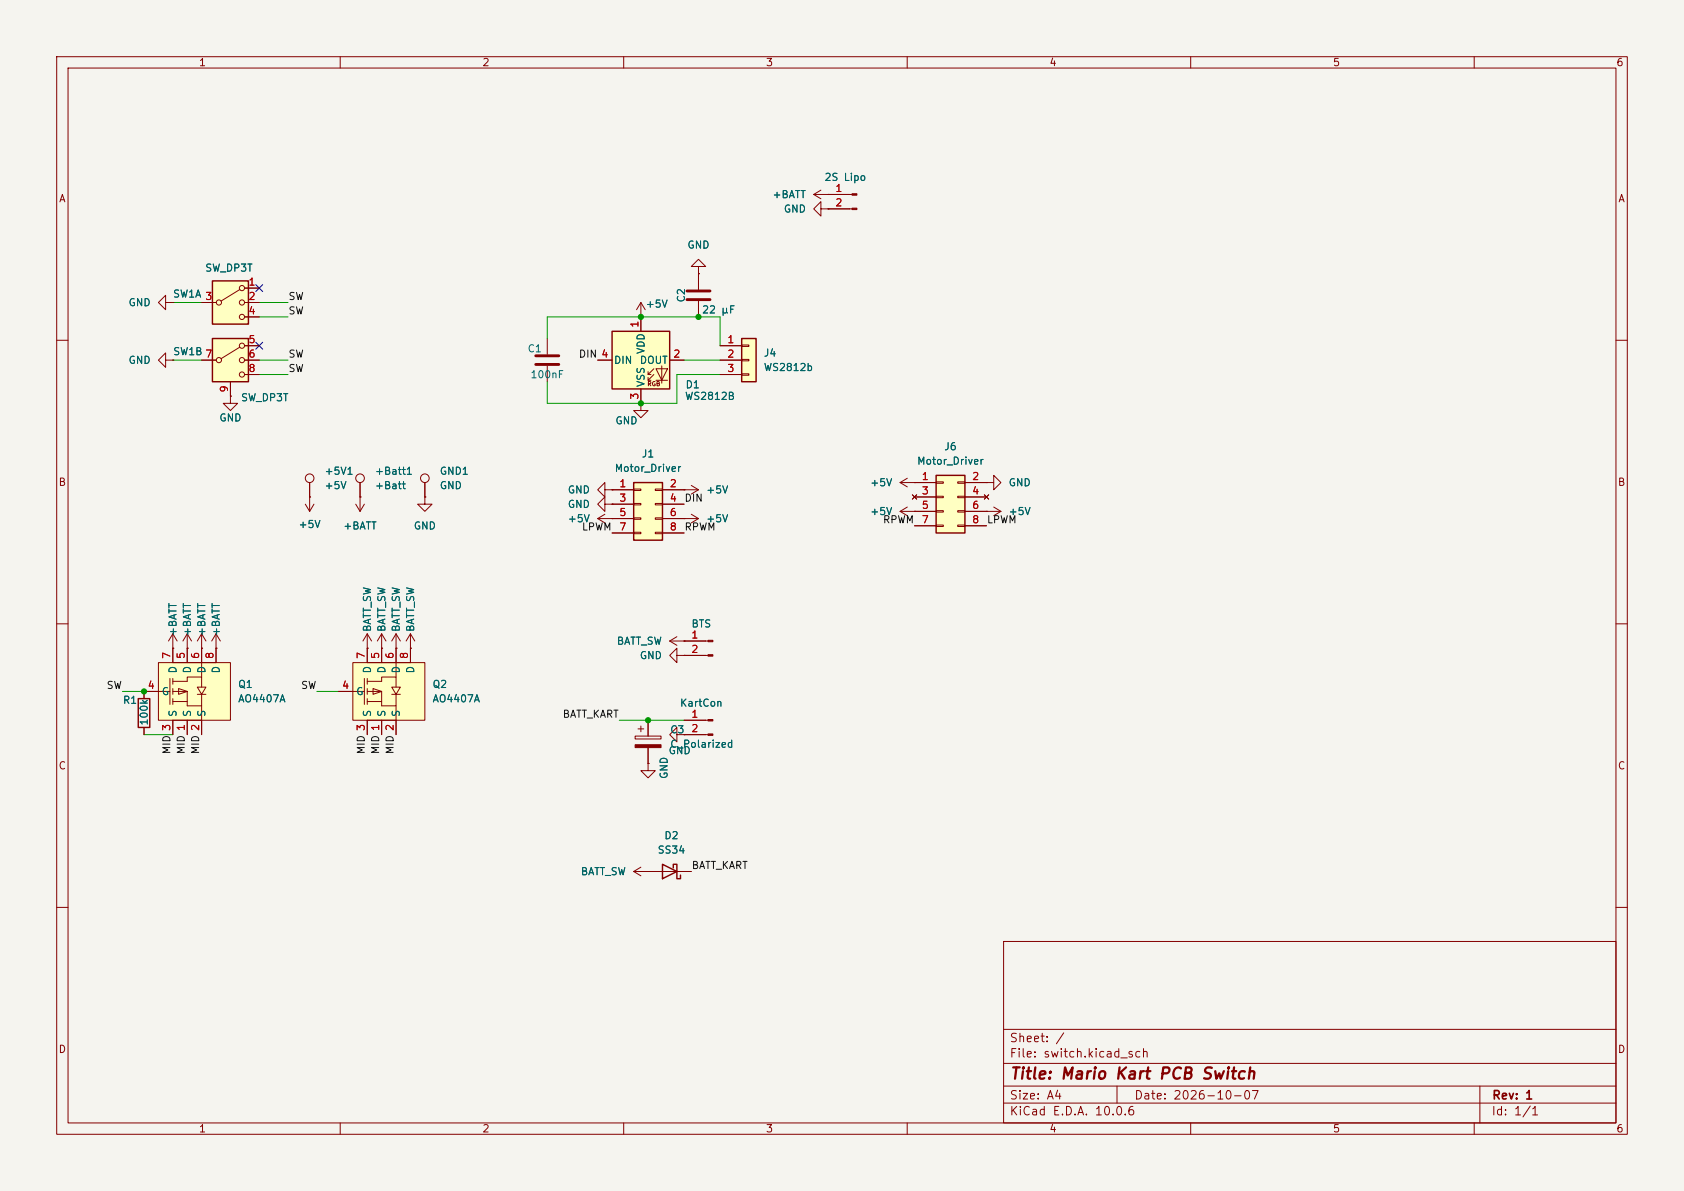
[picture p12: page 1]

8 +BATT +BATT +BATT GND

File: switch.kicad_sch
Title: Mario Kart PCB Switch

Size: A4 | Rev: 1
KiCad E.D.A. 10.0.6 | Id: 1/1

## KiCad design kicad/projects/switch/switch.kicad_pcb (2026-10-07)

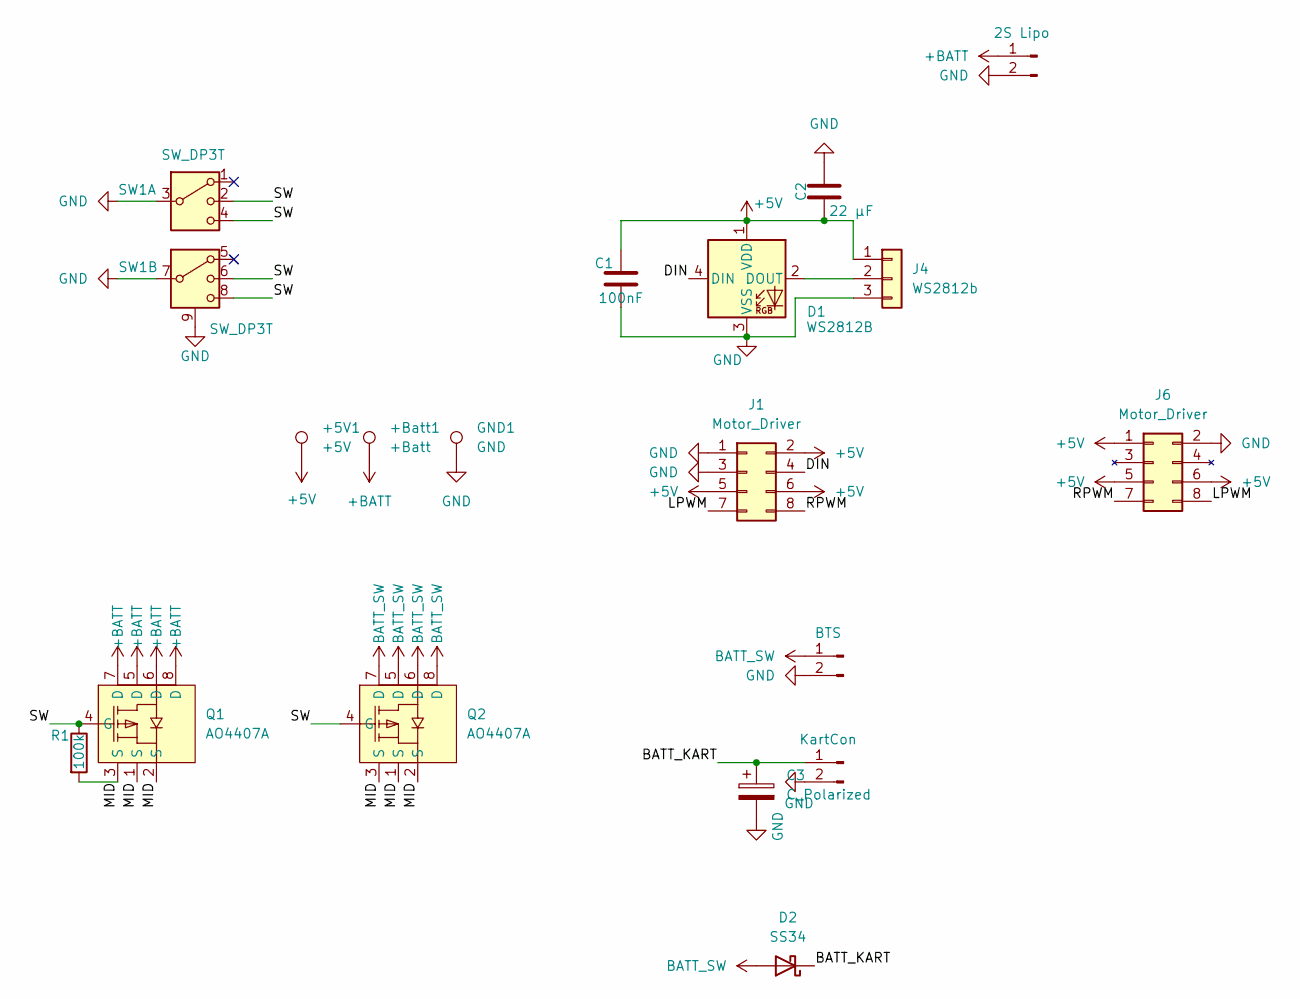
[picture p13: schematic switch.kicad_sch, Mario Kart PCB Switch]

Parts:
+5V1: +5V; TestPoint_Pad_D2.0mm
+Batt1: +Batt; TestPoint_Pad_D2.0mm
C1: 100nF; C_0805_2012Metric_Pad1.18x1.45mm_HandSolder
C2: 22 µF; C_1206_3216Metric
C3: C_Polarized; CP_Elec_12.5x13.5
D1: WS2812B; LED_WS2812B_PLCC4_5.0x5.0mm_P3.2mm
D2: SS34; D_SMA
GND1: GND; TestPoint_Pad_D2.0mm
J1: Motor_Driver; IDC-Header_2x04_P2.54mm_Vertical
J2: BTS; Pins_1x02_P5.0mm_D1.4mm_OD3.0mm
J3: KartCon; SolderWire-0.75sqmm_1x02_P4.8mm_D1.25mm_OD2.3mm
J4: WS2812b; PinHeader_1x03_P2.54mm_Vertical
J5: 2S Lipo; SolderWire-0.75sqmm_1x02_P4.8mm_D1.25mm_OD2.3mm
J6: Motor_Driver; PinHeader_2x04_P2.54mm_Vertical
Q1, Q2: AO4407A; SOIC-8_L4.9-W3.9-P1.27-LS6.0-BL; MPN AO4407A; LCSC Part C16072
R1: 100k; R_0805_2012Metric_Pad1.20x1.40mm_HandSolder
SW1: SW_DP3T; SW_Slide_2P3T_8pin_P2.0mm_MountingLugs

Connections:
+5V: +5V1.1 (1_1), C1.1, C2.1, D1.1 (VDD), J1.2, J1.5, J1.6, J4.1, J6.1, J6.5, J6.6
+BATT: +Batt1.1 (1_1), J5.1, Q1.5 (D), Q1.6 (D), Q1.7 (D), Q1.8 (D)
/BATT_KART: C3.1, D2.1 (K), J3.1
/DIN: D1.4 (DIN), J1.4
/LPWM: J1.7, J6.8
/MID: Q1.1 (S), Q1.2 (S), Q1.3 (S), Q2.1 (S), Q2.2 (S), Q2.3 (S), R1.2
/RPWM: J1.8, J6.7
/SW: Q1.4 (G), Q2.4 (G), R1.1, SW1.2, SW1.4, SW1.6, SW1.8
BATT_SW: D2.2 (A), J2.1, Q2.5 (D), Q2.6 (D), Q2.7 (D), Q2.8 (D)
GND: C1.2, C2.2, C3.2, D1.3 (VSS), GND1.1 (1_1), J1.1, J1.3, J2.2, J3.2, J4.3, J5.2, J6.2, SW1.3, SW1.7, SW1.9 (GND)
unnamed: D1.2 (DOUT), J4.2

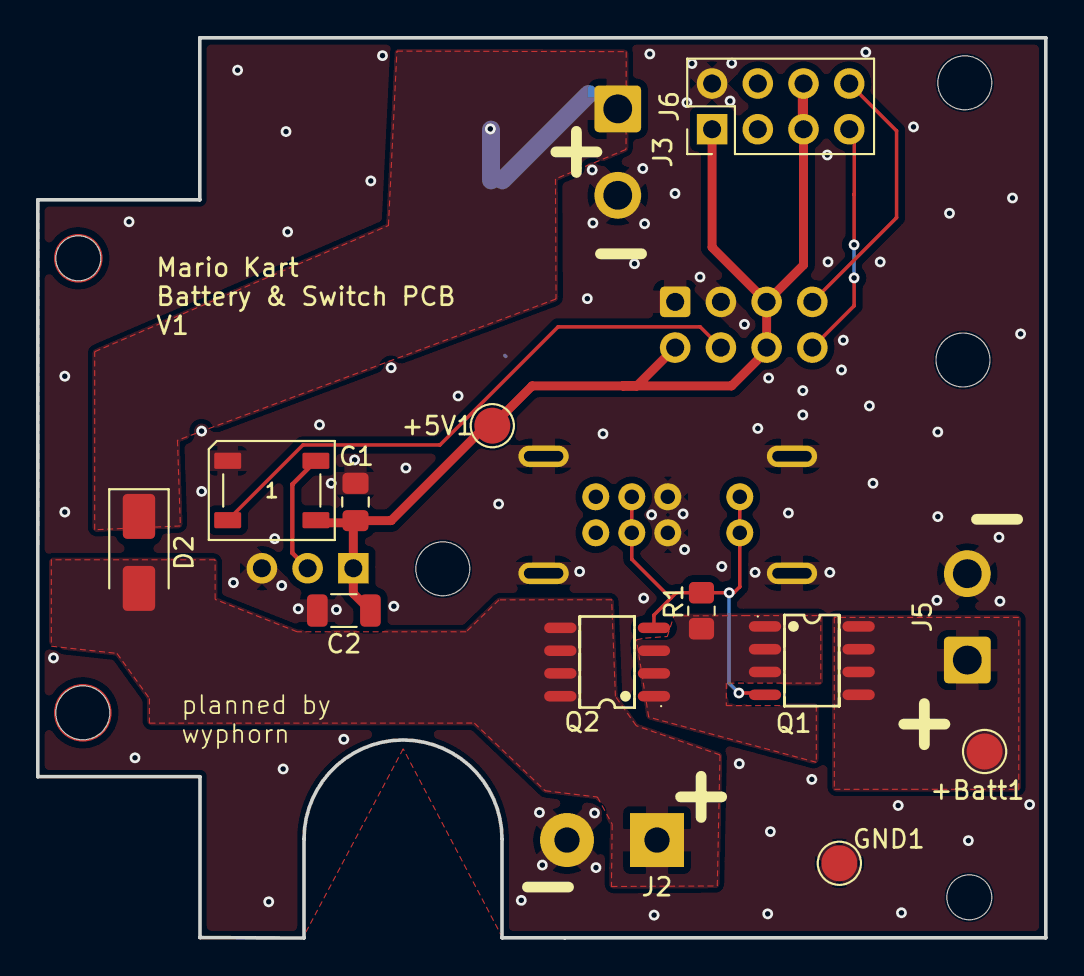
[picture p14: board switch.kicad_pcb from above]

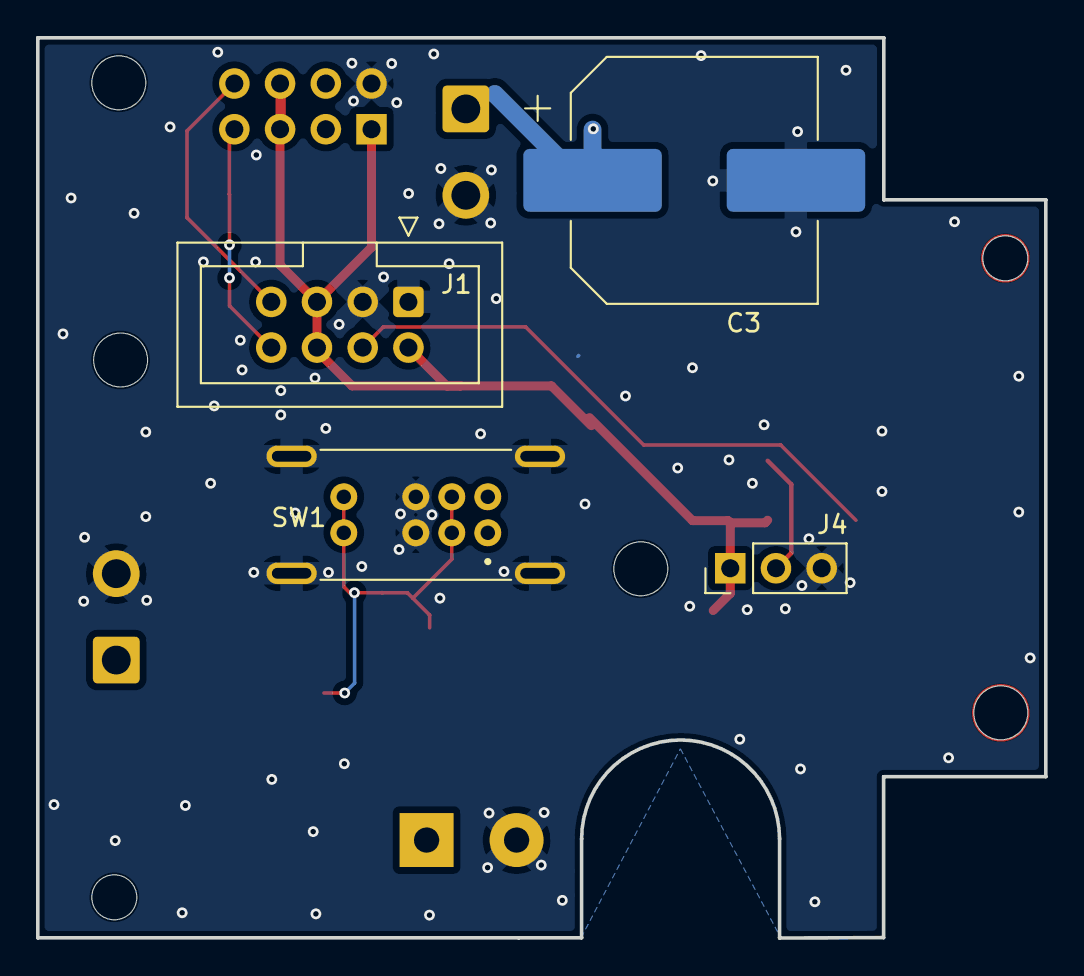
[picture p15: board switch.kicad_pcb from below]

Board: 2 copper layers, 56.0 x 50.0 mm, 20 parts (4 on the bottom side), 11 nets.

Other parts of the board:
H1, H2: MountingHole_3mm

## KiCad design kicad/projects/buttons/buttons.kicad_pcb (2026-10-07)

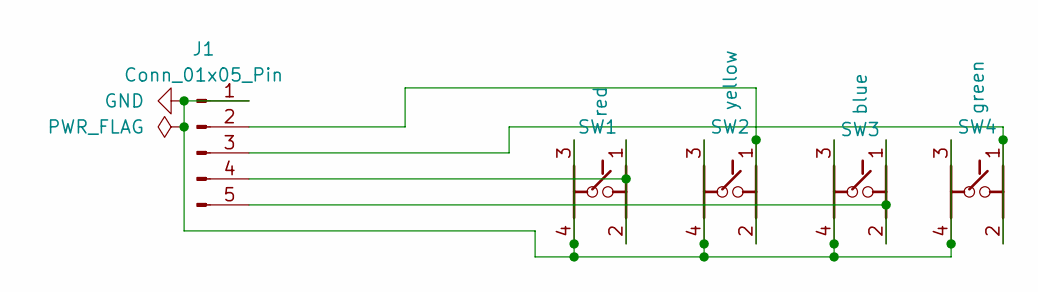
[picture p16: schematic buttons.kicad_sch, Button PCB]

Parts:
J1: Conn_01x05_Pin; JST_XH_S5B-XH-A-1_1x05_P2.50mm_Horizontal
SW1: red; SW_Tactile_12x12mm_THT_P12.5x5.0mm
SW2: yellow; SW_Tactile_12x12mm_THT_P12.5x5.0mm
SW3: blue; SW_Tactile_12x12mm_THT_P12.5x5.0mm
SW4: green; SW_Tactile_12x12mm_THT_P12.5x5.0mm

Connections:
GND: J1.1, SW1.3, SW1.4, SW2.3, SW2.4, SW3.3, SW3.4, SW4.3, SW4.4
unnamed: J1.2, SW2.1, SW2.2
unnamed: J1.3, SW4.1, SW4.2
unnamed: J1.4, SW1.1, SW1.2
unnamed: J1.5, SW3.1, SW3.2

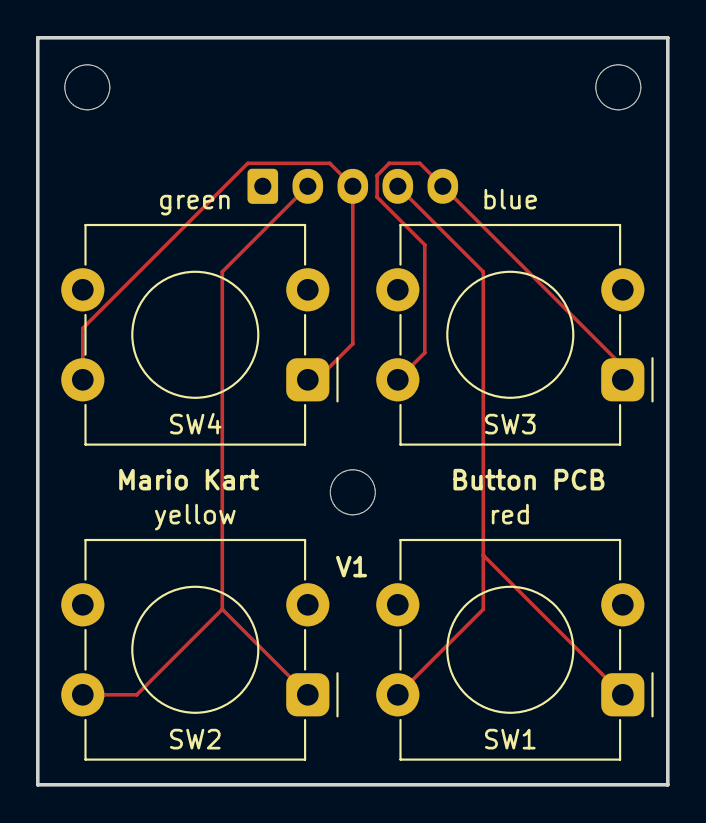
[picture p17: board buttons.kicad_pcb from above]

Board: 2 copper layers, 35.0 x 41.5 mm, 5 parts (1 on the bottom side), 5 nets.

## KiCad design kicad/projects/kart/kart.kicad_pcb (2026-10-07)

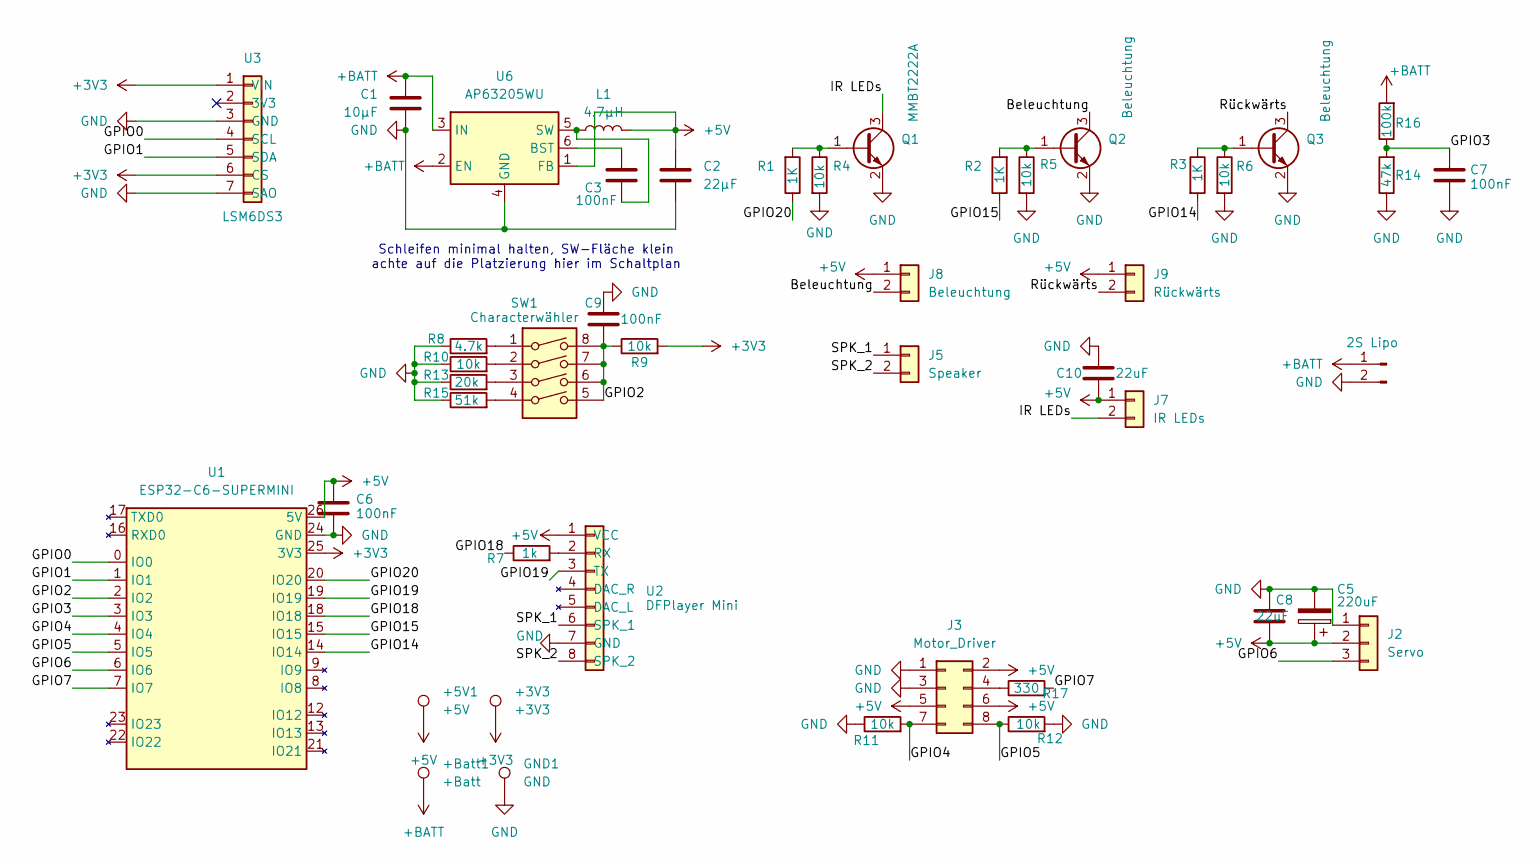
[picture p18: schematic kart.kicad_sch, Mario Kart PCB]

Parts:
+3V3: +3V3; TestPoint_Pad_D2.0mm
+5V1: +5V; TestPoint_Pad_D2.0mm
+Batt1: +Batt; TestPoint_Pad_D2.0mm
C1: 10µF; C_1206_3216Metric_Pad1.33x1.80mm_HandSolder
C2: 22µF; C_1206_3216Metric_Pad1.33x1.80mm_HandSolder
C3, C6, C7, C9: 100nF; C_0805_2012Metric_Pad1.18x1.45mm_HandSolder
C5: 220uF; CP_Elec_6.3x5.4
C8, C10: 22uF; C_1206_3216Metric_Pad1.33x1.80mm_HandSolder
GND1: GND; TestPoint_Pad_D2.0mm
J2: Servo; JST_XH_B3B-XH-A_1x03_P2.50mm_Vertical
J3: Motor_Driver; IDC-Header_2x04_P2.54mm_Vertical
J4: 2S Lipo; SolderWire-0.75sqmm_1x02_P4.8mm_D1.25mm_OD2.3mm
J5: Speaker; PinHeader_1x02_P2.54mm_Vertical
J7: IR LEDs; PinHeader_1x02_P2.54mm_Vertical
J8: Beleuchtung; PinHeader_1x02_P2.54mm_Vertical
J9: Rückwärts; PinHeader_1x02_P2.54mm_Vertical
L1: 4.7µH; L_Bourns_SRN6045TA
Q1: MMBT2222A; SOT-23_Handsoldering
Q2, Q3: Beleuchtung; SOT-23_Handsoldering
R1, R2, R3: 1K; R_0805_2012Metric_Pad1.20x1.40mm_HandSolder
R4, R5, R6, R9, R10, R11, R12: 10k; R_0805_2012Metric_Pad1.20x1.40mm_HandSolder
R7: 1k; R_0805_2012Metric_Pad1.20x1.40mm_HandSolder
R8: 4.7k; R_0805_2012Metric_Pad1.20x1.40mm_HandSolder
R13: 20k; R_0805_2012Metric_Pad1.20x1.40mm_HandSolder
R14: 47k; R_0805_2012Metric_Pad1.20x1.40mm_HandSolder
R15: 51k; R_0805_2012Metric_Pad1.20x1.40mm_HandSolder
R16: 100k; R_0805_2012Metric_Pad1.20x1.40mm_HandSolder
R17: 330; R_0805_2012Metric_Pad1.20x1.40mm_HandSolder
SW1: Characterwähler; SW_DIP_SPSTx04_Piano_10.8x11.72mm_W7.62mm_P2.54mm
U1: ESP32-C6-SUPERMINI; ESP32-C6-SuperMini_2x10_P2.54mm_Row15.24mm
U2: DFPlayer Mini; PinHeader_1x08_P2.54mm_Vertical
U3: LSM6DS3; PinHeader_1x07_P2.54mm_Vertical
U6: AP63205WU; TSOT-23-6

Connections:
+3V3: +3V3.1 (1_1), R9.2, U1.25 (3V3), U3.1 (VIN), U3.6 (CS)
+5V: +5V1.1, C2.1, C5.1, C6.1, C8.2, C10.2, J2.2, J3.2, J3.5, J3.6, J7.1, J8.1, J9.1, L1.2, U1.26 (5V), U2.1 (VCC), U6.1 (FB); also elsewhere on the board
+BATT: +Batt1.1, C1.1, J4.1, R16.2, U6.2 (EN), U6.3 (IN); also elsewhere on the board
/Beleuchtung: J8.2, Q2.3 (C)
/GPIO0: U1.0 (IO0), U3.4 (SCL)
/GPIO1: U1.1 (IO1), U3.5 (SDA)
/GPIO2: C9.2, R9.1, SW1.5, SW1.6, SW1.7, SW1.8, U1.2 (IO2)
/GPIO3: C7.1, R14.2, R16.1, U1.3 (IO3)
/GPIO4: J3.7, R11.2, U1.4 (IO4)
/GPIO5: J3.8, R12.1, U1.5 (IO5)
/GPIO6: J2.3, U1.6 (IO6)
/GPIO7: R17.2, U1.7 (IO7)
/GPIO14: R3.2, U1.14 (IO14)
/GPIO15: R2.1, U1.15 (IO15)
/GPIO18: R7.1, U1.18 (IO18)
/GPIO19: U1.19 (IO19), U2.3 (TX)
/GPIO20: R1.1, U1.20 (IO20)
/IR LEDs: J7.2, Q1.3 (C)
/Rückwärts: J9.2, Q3.3 (C)
/SPK_1: J5.1, U2.6 (SPK_1)
/SPK_2: J5.2, U2.8 (SPK_2)
GND: C1.2, C2.2, C5.2, C6.2, C7.2, C8.1, C9.1, C10.1, GND1.1, J2.1, J3.1, J3.3, J4.2, Q1.2 (E), Q2.2 (E), Q3.2 (E), R4.2, R5.2, R6.2, R8.1, R10.1, R11.1, R12.2, R13.1, R14.1, R15.1, U1.24 (GND), U2.7 (GND), U3.3 (GND), U3.7 (SAO), U6.4 (GND); also elsewhere on the board
unnamed: J3.4, R17.1
unnamed: Q1.1 (B), R1.2, R4.1
unnamed: Q2.1 (B), R2.2, R5.1
unnamed: Q3.1 (B), R3.1, R6.1
unnamed: R8.2, SW1.1
unnamed: R10.2, SW1.2
unnamed: R13.2, SW1.3
unnamed: R15.2, SW1.4
unnamed: R7.2, U2.2 (RX)
unnamed: C3.1, U6.6 (BST)
unnamed: C3.2, L1.1, U6.5 (SW)

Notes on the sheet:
Schleifen minimal halten, SW-Fläche klein achte auf die Platzierung hier im Schaltplan

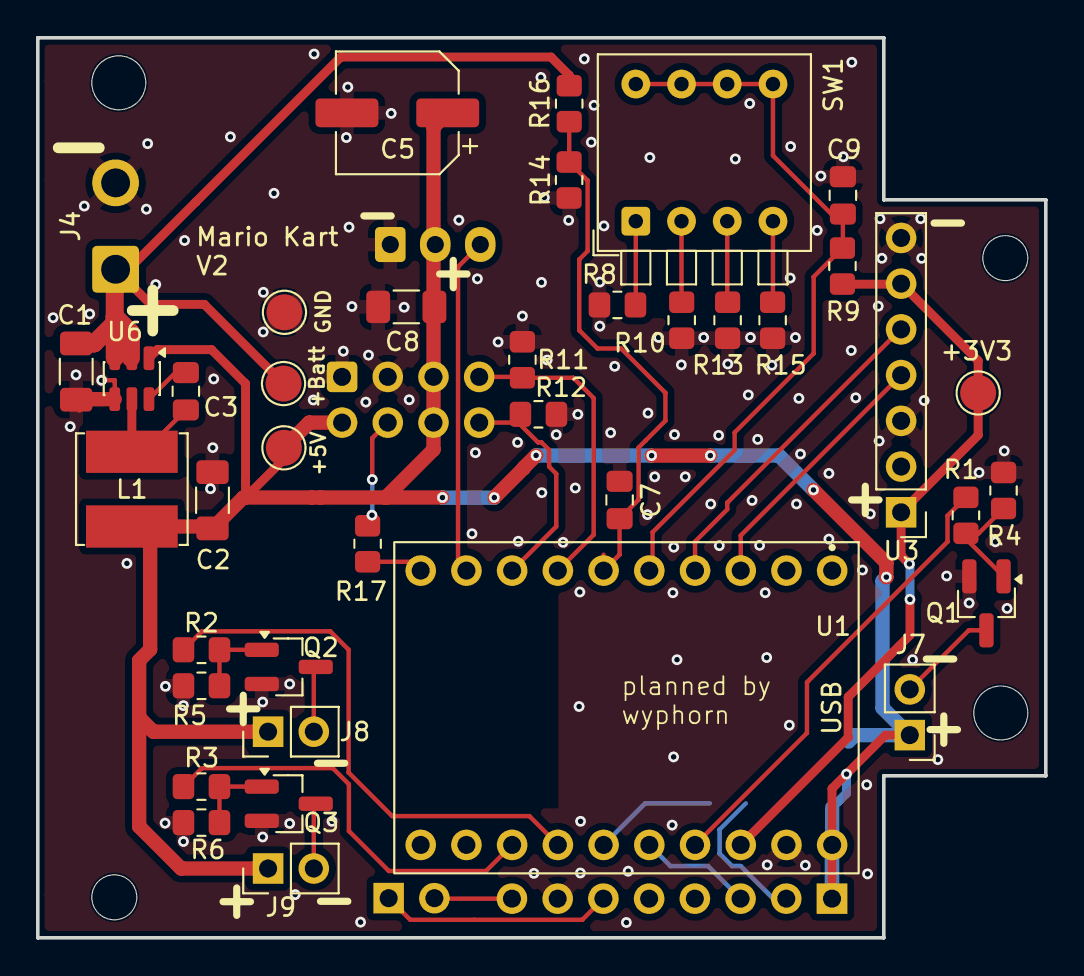
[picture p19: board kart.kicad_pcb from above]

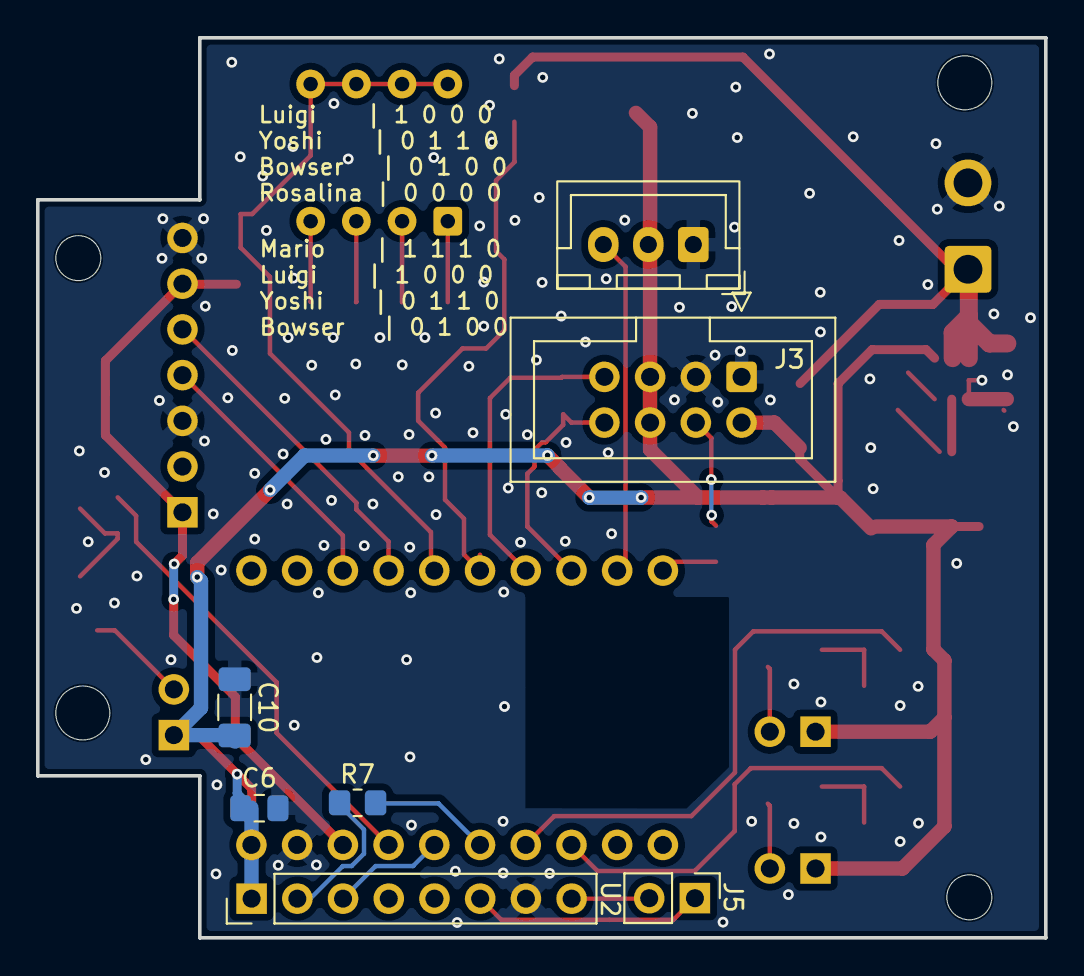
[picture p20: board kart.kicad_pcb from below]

Board: 2 copper layers, 56.0 x 50.0 mm, 46 parts (7 on the bottom side), 33 nets.

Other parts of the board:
+5V: +5V; TestPoint_Pad_D2.0mm
+Batt: +Batt; TestPoint_Pad_D2.0mm
GND: GND; TestPoint_Pad_D2.0mm

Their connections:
+5V: +5V.1 (1_1); also elsewhere on the board
+BATT: +Batt.1 (1_1); also elsewhere on the board
GND: GND.1 (1_1); also elsewhere on the board

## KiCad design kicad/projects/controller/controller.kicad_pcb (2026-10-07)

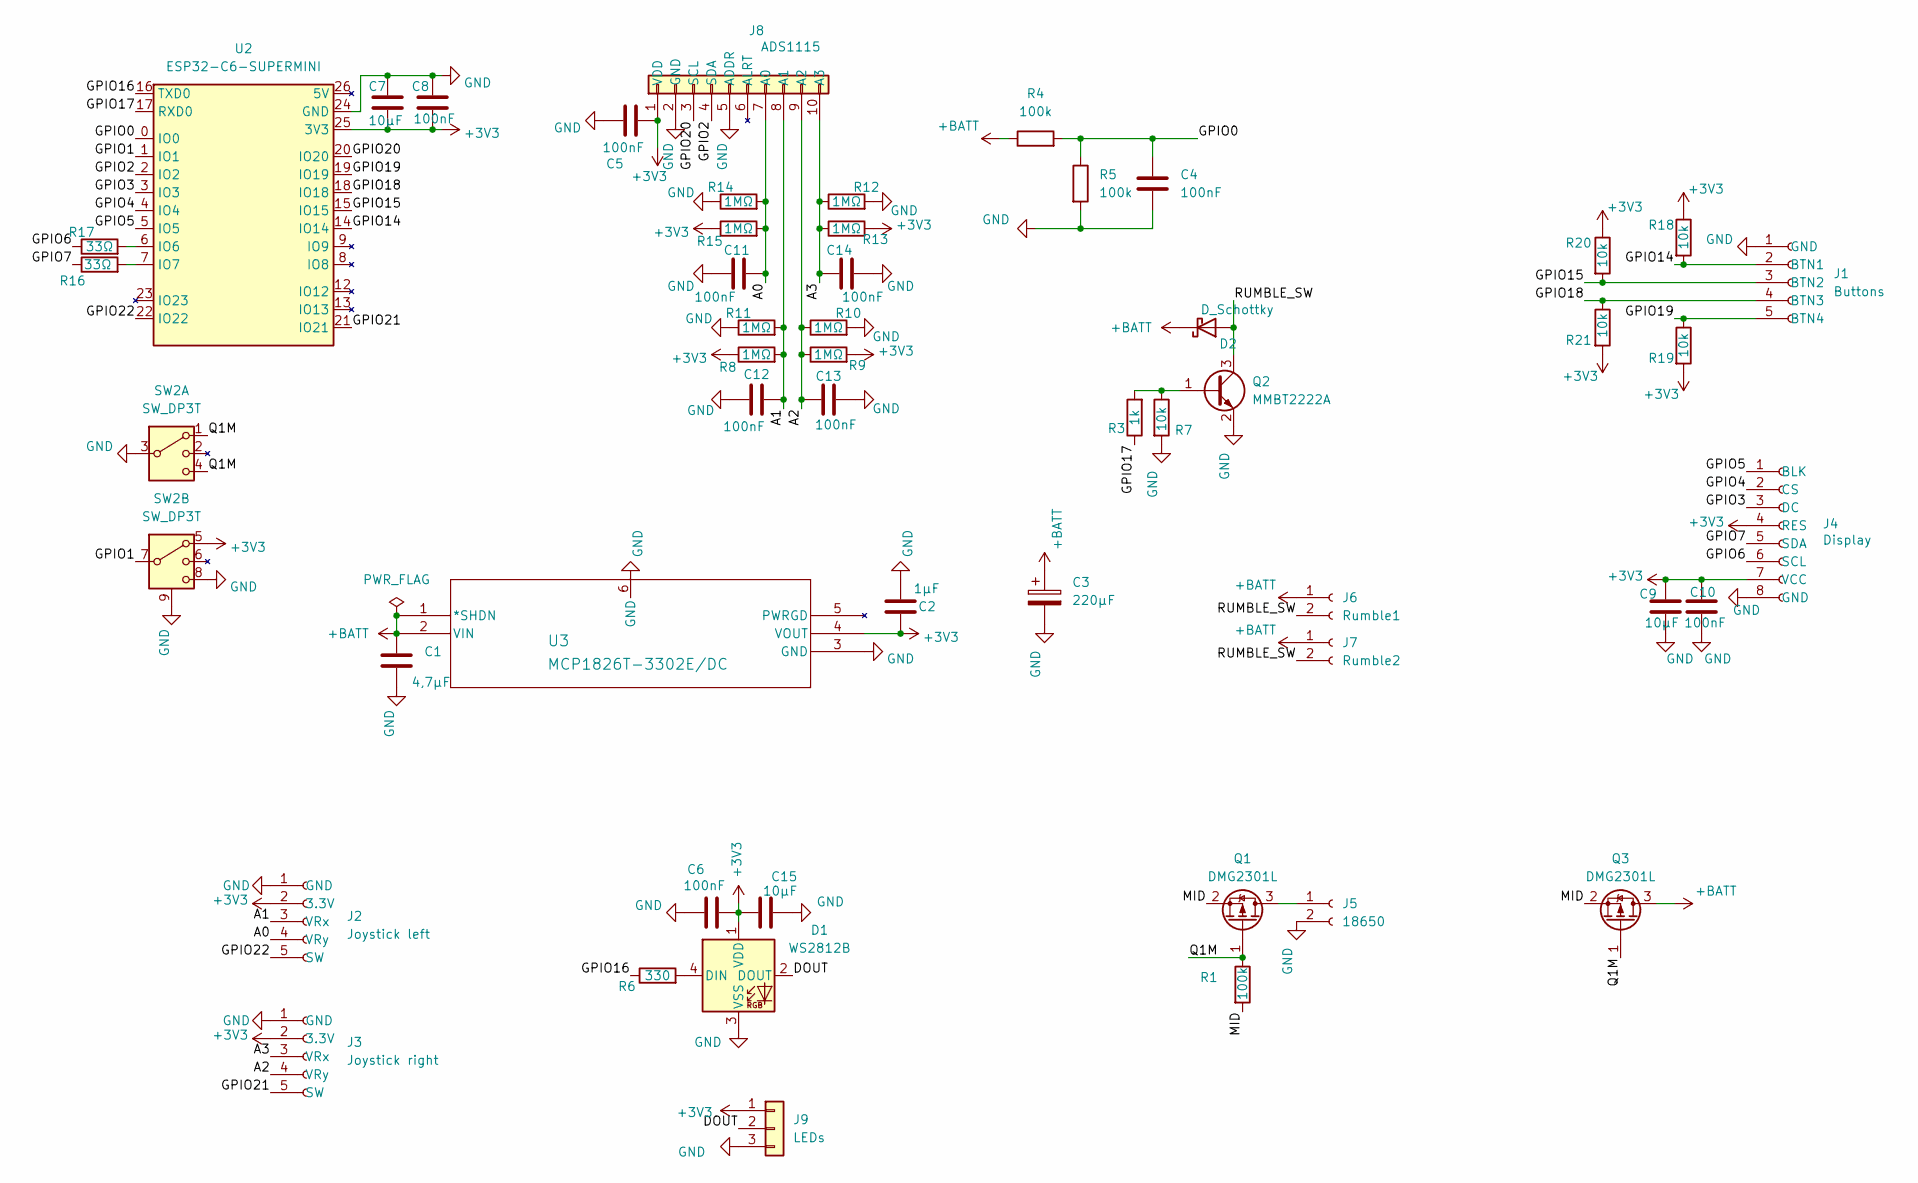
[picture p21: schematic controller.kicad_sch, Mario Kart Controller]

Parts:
C1: 4,7µF; C_0805_2012Metric_Pad1.18x1.45mm_HandSolder
C2: 1µF; C_0805_2012Metric_Pad1.18x1.45mm_HandSolder
C3: 220µF; CP_Elec_6.3x5.4
C4, C5, C6, C8, C10, C11, C12, C13, C14: 100nF; C_0805_2012Metric_Pad1.18x1.45mm_HandSolder
C7, C9, C15: 10µF; C_1206_3216Metric_Pad1.33x1.80mm_HandSolder
D1: WS2812B; LED_WS2812B_PLCC4_5.0x5.0mm_P3.2mm
D2: D_Schottky; D_SMA_Handsoldering
J1: Buttons; PinHeader_1x05_P2.54mm_Vertical
J2: Joystick left; JST_XH_S5B-XH-A-1_1x05_P2.50mm_Horizontal
J3: Joystick right; JST_XH_S5B-XH-A-1_1x05_P2.50mm_Horizontal
J4: Display; JST_XH_S8B-XH-A-1_1x08_P2.50mm_Horizontal
J5: 18650; SolderWire-0.75sqmm_1x02_P4.8mm_D1.25mm_OD2.3mm
J6: Rumble1; PinHeader_1x02_P2.54mm_Vertical
J7: Rumble2; PinHeader_1x02_P2.54mm_Vertical
J8: ADS1115; PinHeader_1x10_P2.54mm_Vertical
J9: LEDs; PinHeader_1x03_P2.54mm_Vertical
Q1, Q3: DMG2301L; SOT-23_Handsoldering
Q2: MMBT2222A; SOT-23_Handsoldering
R1, R4, R5: 100k; R_0805_2012Metric_Pad1.20x1.40mm_HandSolder
R3: 1k; R_0805_2012Metric_Pad1.20x1.40mm_HandSolder
R6: 330; R_0805_2012Metric_Pad1.20x1.40mm_HandSolder
R7, R18, R19, R20, R21: 10k; R_0805_2012Metric_Pad1.20x1.40mm_HandSolder
R8, R9, R10, R11, R12, R13, R14, R15: 1MΩ; R_0805_2012Metric_Pad1.20x1.40mm_HandSolder
R16, R17: 33Ω; R_0805_2012Metric_Pad1.20x1.40mm_HandSolder
SW2: SW_DP3T; SW_Slide_2P3T_8pin_P2.0mm_MountingLugs
U2: ESP32-C6-SUPERMINI; ESP32-C6-SuperMini_2x10_P2.54mm_Row15.24mm
U3: MCP1826T-3302E/DC; SOT-223_5MC_MCH

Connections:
+3V3: C2.1, C5.1, C6.1, C7.2, C8.2, C9.1, C10.1, C15.1, D1.1 (VDD), J2.2 (3.3V), J3.2 (3.3V), J4.4 (RES), J4.7 (VCC), J8.1 (VDD), J9.1, R8.1, R9.2, R13.2, R15.1, R18.1, R19.2, R20.1, R21.2, SW2.5, U2.25 (3V3), U3.4 (VOUT)
+BATT: C1.1, C3.1, D2.1 (K), J6.1, J7.1, Q3.3 (D), R4.1, U3.1 (*SHDN), U3.2 (VIN)
/A0: C11.2, J2.4 (VRy), J8.7 (A0), R14.2, R15.2
/A1: C12.1, J2.3 (VRx), J8.8 (A1), R8.2, R11.2
/A2: C13.1, J3.4 (VRy), J8.9 (A2), R9.1, R10.1
/A3: C14.1, J3.3 (VRx), J8.10 (A3), R12.1, R13.1
/DOUT: D1.2 (DOUT), J9.2
/GPIO0: C4.1, R4.2, R5.1, U2.0 (IO0)
/GPIO1: SW2.7, U2.1 (IO1)
/GPIO2: J8.4 (SDA), U2.2 (IO2)
/GPIO3: J4.3 (DC), U2.3 (IO3)
/GPIO4: J4.2 (CS), U2.4 (IO4)
/GPIO5: J4.1 (BLK), U2.5 (IO5)
/GPIO6: J4.6 (SCL), R17.1
/GPIO7: J4.5 (SDA), R16.1
/GPIO14: J1.2 (BTN1), R18.2, U2.14 (IO14)
/GPIO15: J1.3 (BTN2), R20.2, U2.15 (IO15)
/GPIO16: R6.1, U2.16 (TXD0)
/GPIO17: R3.1, U2.17 (RXD0)
/GPIO18: J1.4 (BTN3), R21.1, U2.18 (IO18)
/GPIO19: J1.5 (BTN4), R19.1, U2.19 (IO19)
/GPIO20: J8.3 (SCL), U2.20 (IO20)
/GPIO21: J3.5 (SW), U2.21 (IO21)
/GPIO22: J2.5 (SW), U2.22 (IO22)
/MID: Q1.2 (S), Q3.2 (S), R1.2
/Q1M: Q1.1 (G), Q3.1 (G), R1.1, SW2.1, SW2.4
/RUMBLE_SW: D2.2 (A), J6.2, J7.2, Q2.3 (C)
GND: C1.2, C2.2, C3.2, C4.2, C5.2, C6.2, C7.1, C8.1, C9.2, C10.2, C11.1, C12.2, C13.2, C14.2, C15.2, D1.3 (VSS), J1.1 (GND), J2.1 (GND), J3.1 (GND), J4.8 (GND), J5.2, J8.2 (GND), J8.5 (ADDR), J9.3, Q2.2 (E), R5.2, R7.2, R10.2, R11.1, R12.2, R14.1, SW2.3, SW2.8, SW2.9 (GND), U2.24 (GND), U3.3 (GND), U3.6 (GND)
unnamed: D1.4 (DIN), R6.2
unnamed: J5.1, Q1.3 (D)
unnamed: Q2.1 (B), R3.2, R7.1
unnamed: R17.2, U2.6 (IO6)
unnamed: R16.2, U2.7 (IO7)

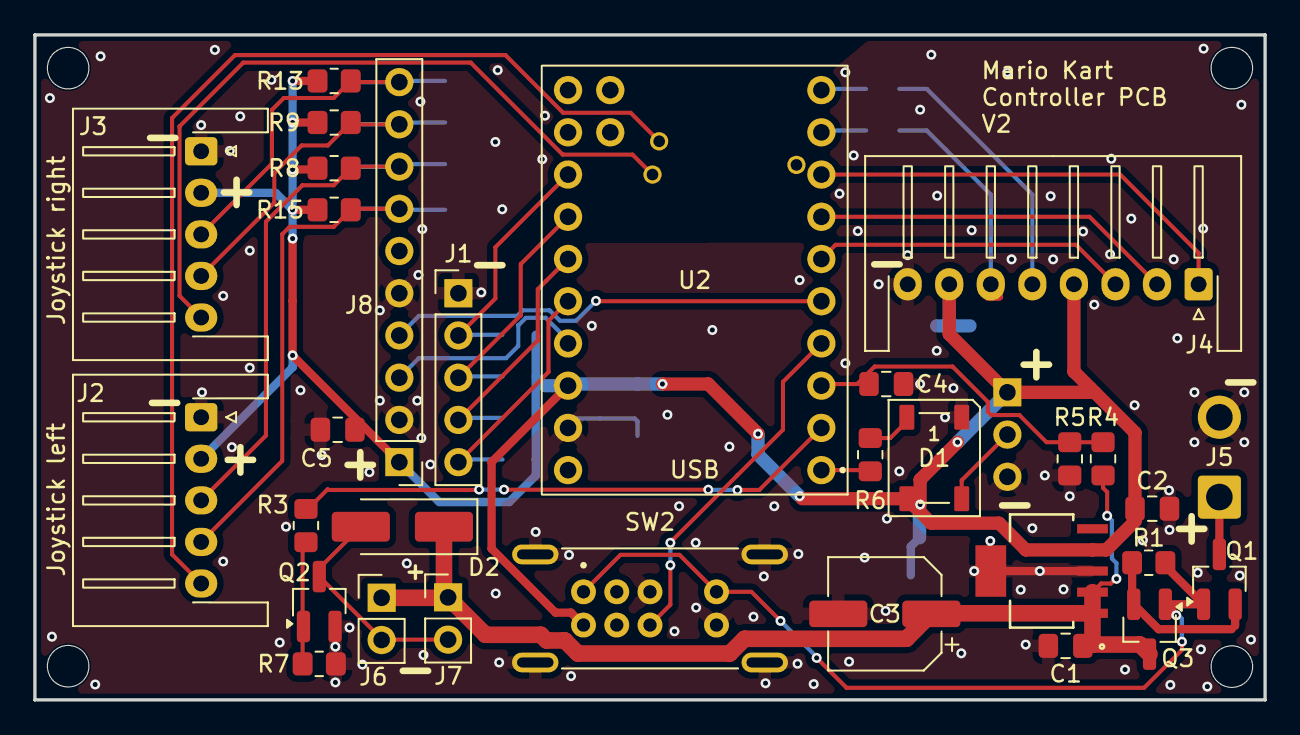
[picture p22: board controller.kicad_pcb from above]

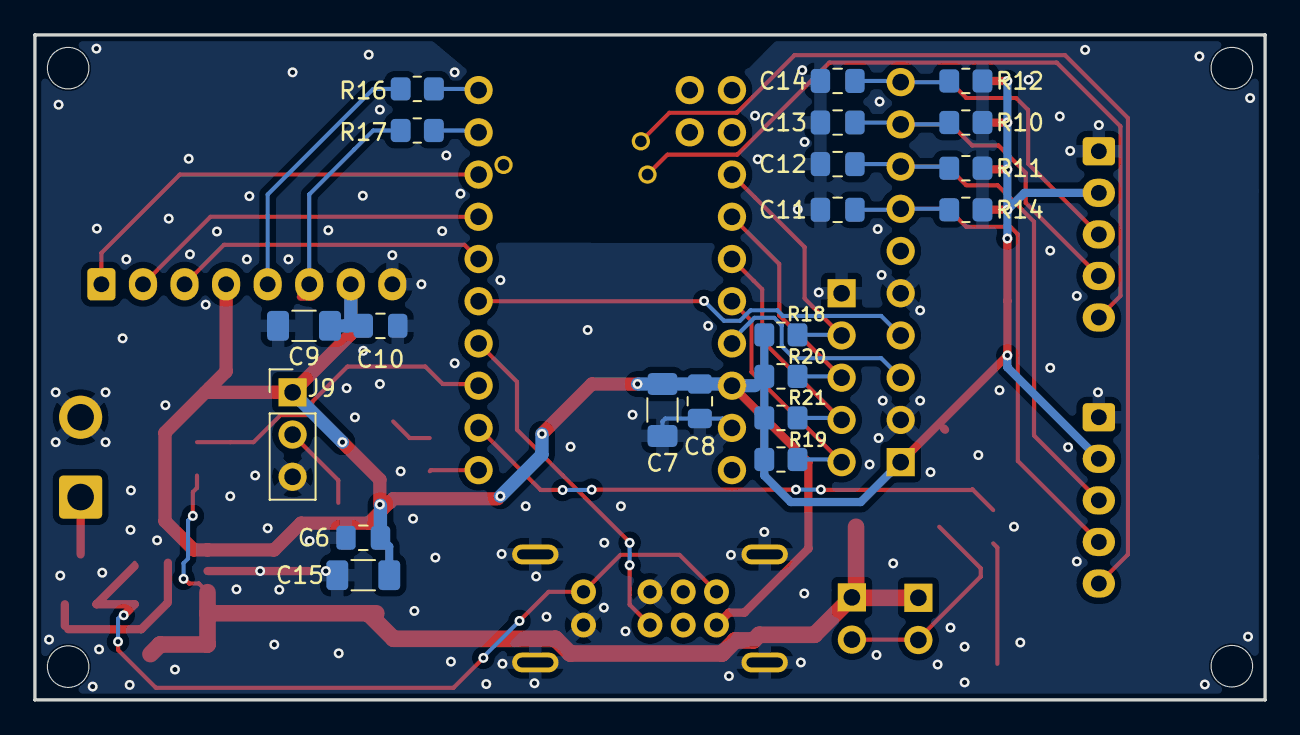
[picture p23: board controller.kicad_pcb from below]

Board: 2 copper layers, 74.0 x 40.0 mm, 52 parts (21 on the bottom side), 33 nets.

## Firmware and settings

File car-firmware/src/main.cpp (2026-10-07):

#include <Arduino.h>
#include <Wire.h>
#include <EEPROM.h>
#include <esp_now.h>
#include <WiFi.h>
#include <esp_wifi.h>
#include <esp_sleep.h>
#include <driver/gpio.h>
#include <Adafruit_NeoPixel.h>
#include <DFRobotDFPlayerMini.h>
#include <ArduinoOTA.h>
#include "mk_protocol.h"
#include "mk_clock_guard.h"
#include "mk_watchdog.h"
#include "star_envelope.h"   // erzeugt von tools/make_star_envelope.py
#if __has_include("mk_secrets.h")
#include "mk_secrets.h"   // WLAN für den Update-Modus, Vorlage: mk_secrets.example.h
#endif

// ── Sound tables ─────────────────────────────────────────────────────────────
// Track numbers match DFPlayer filenames: track 2 → 002.mp3.
// Folder order matches gCharFolder (1=Mario … 8=Rosalina).
// Add/remove track numbers as you place files on the SD card.
// Empty array = nothing plays for that mood/character.

struct CharSounds {
    const uint8_t* joy;   uint8_t joyCount;
    const uint8_t* sad;   uint8_t sadCount;
};

// Mario (folder 01)
static const uint8_t kJoy_Mario[] = {1,2,4};
static const uint8_t kSad_Mario[] = {3,5};

// Yoshi (folder 03)
static const uint8_t kJoy_Yoshi[] = {1,2,4};
static const uint8_t kSad_Yoshi[] = {3,5};

// Bowser (folder 04)
static const uint8_t kJoy_Bowser[] = {1,4};
static const uint8_t kSad_Bowser[] = {2,3,5};

// DK (folder 05)
static const uint8_t kJoy_DK[] = {1,3,5};
static const uint8_t kSad_DK[] = {2,4};

// Luigi (folder 02)
static const uint8_t kJoy_Luigi[] = {1,2,4};
static const uint8_t kSad_Luigi[] = {3,5};

// Peach (folder 06)
static const uint8_t kJoy_Peach[] = {1,2,4};
static const uint8_t kSad_Peach[] = {3,5};

// Toad (folder 07)
static const uint8_t kJoy_Toad[] = {1,2,4};
static const uint8_t kSad_Toad[] = {4,5};

// Rosalina (folder 08)
static const uint8_t kJoy_Rosalina[] = {1,2,4};
static const uint8_t kSad_Rosalina[] = {4,5};

// ── Game sounds (folder 09) ───────────────────────────────────────────────────
// Charakter-unabhängige Sounds, ausgelöst durch Spielereignisse (Item etc.).
// Tracknummer = Dateiname: SND_BANANA 1 → 001.mp3, SND_STAR 7 → 007.wav, …
// 0 = nicht belegt / noch keine Datei vorhanden.

static constexpr uint8_t FOLDER_GAME  = 9;

static constexpr uint8_t SND_STAR     = 7;   // 007.wav – Stern (geloopt, 12.4 s)
static constexpr uint8_t SND_BANANA   = 1;   // 001.mp3 – Banane ablegen
static constexpr uint8_t SND_SHELL    = 0;   // noch nicht belegt
static constexpr uint8_t SND_BOOST    = 0;   // noch nicht belegt
static constexpr uint8_t SND_FINISH   = 0;   // noch nicht belegt

#define SOUNDS(chr) { kJoy_##chr, sizeof(kJoy_##chr), kSad_##chr, sizeof(kSad_##chr) }
static const CharSounds kSounds[8] = {
    SOUNDS(Mario),
    SOUNDS(Luigi),
    SOUNDS(Yoshi),
    SOUNDS(Bowser),
    SOUNDS(DK),
    SOUNDS(Peach),
    SOUNDS(Toad),
    SOUNDS(Rosalina),
};
#undef SOUNDS

// ── Pins ─────────────────────────────────────────────────────────────────────
static constexpr int PIN_ADC_CHAR = 2;
static constexpr int PIN_DF_TX    = 18;  // ESP32 TX → DFPlayer RX
static constexpr int PIN_DF_RX    = 19;  // ESP32 RX ← DFPlayer TX
static constexpr int PIN_SCL      = 0;
static constexpr int PIN_SDA      = 1;
// Kart-Board V2 hat fürs Routing eine andere Pinbelegung (env car_v2,
// -DKART_REV=2), siehe CLAUDE.md. Falsche Firmware aufs falsche Board: Motor
// steht oder läuft falsch, LEDs dunkel — und der Servo bekommt ggf. das
// Motor-PWM und fährt an den Anschlag. Der Bootlog nennt die Board-Version.
#ifndef KART_REV
#define KART_REV 1
#endif
#if KART_REV == 2
// V2 (Layout 2026-10-04 gedreht): LED-Daten gehen über J3 Pin 4 zum
// Schalter-Platinchen (Status-LED, dahinter die Figur).
static constexpr int PIN_ADC_BAT  = 3;
static constexpr int PIN_LPWM     = 4;
static constexpr int PIN_RPWM     = 5;
static constexpr int PIN_SERVO    = 6;
static constexpr int PIN_LED      = 7;
static constexpr int PIN_IR       = 20;
#else
static constexpr int PIN_ADC_BAT  = 4;
static constexpr int PIN_RPWM     = 5;
static constexpr int PIN_LPWM     = 6;
static constexpr int PIN_SERVO    = 7;
static constexpr int PIN_LED      = 20;
static constexpr int PIN_IR       = 3;
#endif
static constexpr int PIN_LIGHT_MAIN = 15;  // Front weiß + Heck rot (ein NPN)
// Hauptlicht über PWM statt nur an/aus — im Stern-Modus pulsiert es zur
// Lautstärke des Lieds. Der NPN schaltet 1 kHz problemlos, das Auge sieht kein
// Flackern.
static constexpr uint32_t LIGHT_PWM_HZ   = 1000;
static constexpr uint8_t  LIGHT_PWM_BITS = 8;
static void lightMainWrite(uint8_t duty) {
    static int last = -1;
    if (duty == last) return;
    last = duty;
    ledcWrite(PIN_LIGHT_MAIN, duty);
}
static constexpr int PIN_LIGHT_REV  = 14;  // Heck weiß, Rückwärtsgang

// ── Constants ─────────────────────────────────────────────────────────────────
static constexpr int LED_COUNT    = 11;
static constexpr uint8_t LSM_ADDR = 0x6A;

// Servo limits with 5° mechanical buffer (1000–2000 → 1050–1950)
static constexpr int SERVO_MIN_US = 1050;
static constexpr int SERVO_MAX_US = 1950;
static constexpr int SERVO_MID_US = 1500;
// Servo direkt über LEDC statt ESP32Servo — die Bibliothek bindet den Pin unter
// Core 3.x doppelt an und meldet bei jedem Start einen falschen Fehler.
// 50 Hz = 20000 µs Periode, 14 bit → 16384 Stufen, ~1.2 µs Auflösung.
static constexpr uint32_t SERVO_FREQ_HZ   = 50;
static constexpr uint8_t  SERVO_RES_BITS  = 14;
static constexpr uint32_t SERVO_PERIOD_US = 1000000 / SERVO_FREQ_HZ;

static void servoWriteUs(int us) {
    // Nur bei Änderung schreiben: jedes ledcWrite stößt eine Aktualisierung
    // der PWM an, bei mehreren Schreibvorgängen pro Periode kann der Servo
    // einen Zwischenwert als Puls bekommen und zucken.
    static uint32_t lastDuty = UINT32_MAX;
    uint32_t duty = (uint32_t)us * ((1u << SERVO_RES_BITS) - 1) / SERVO_PERIOD_US;
    if (duty == lastDuty) return;
    lastDuty = duty;
    ledcWrite(PIN_SERVO, duty);
}

// ── Battery thresholds (2S LiPo / 2× 18650) ──────────────────────────────────
// Spannungsteiler: R1 (VBat→ADC) + R2 (ADC→GND) — Werte anpassen wenn verdrahtet!
static constexpr float BAT_R1          = 100000.0f;
static constexpr float BAT_R2          =  47000.0f;
static constexpr float BAT_DIVIDER_INV = (BAT_R1 + BAT_R2) / BAT_R2;
// V2: Der Teiler misst hinter der Puffer-Diode (Schottky SS34) auf dem
// Schalter-Platinchen, also um deren Durchlassspannung zu niedrig. Typisch
// 0.3 V bei den 0.3–1 A der Elektronik — ohne Ausgleich griffe der
// Tiefentladeschutz schon bei echten ~6.7 V statt 6.4 V.
// Nachbau: D2 durch Drahtbrücke ersetzt → hier 0.0f eintragen, sonst greift
// der Tiefentladeschutz erst bei echten ~6.1 V.
#if KART_REV == 2
static constexpr float BAT_DIODE_DROP_V = 0.30f;
#else
static constexpr float BAT_DIODE_DROP_V = 0.0f;
#endif
static constexpr float BAT_WARN_V      = 6.6f;  // 3.3V/Zelle
// Tiefentladeschutz für ungeschützte 18650: liegt der Akku BAT_OFF_SAMPLES
// Messungen in Folge (1 Hz = 30 s) unter BAT_OFF_V, geht das Auto in Deep Sleep
// ohne Weckquelle. Jede Messung zählt, auch unter Last — im Rennen steht das
// Auto nie lange genug. Solange der Akku Reserve hat, erholt sich die Spannung
// beim Gaswegnehmen über die Schwelle und setzt den Zähler zurück; erst wenn
// auch die entlastete Spannung darunter bleibt, wird abgeschaltet. 30 s
// Volllast am Stück können früher auslösen — kostet Laufzeit, nicht die Zelle.
static constexpr float   BAT_OFF_V       = 6.4f;  // 3.2V/Zelle
static constexpr uint8_t BAT_OFF_SAMPLES = 30;

// ── EEPROM layout ─────────────────────────────────────────────────────────────
static constexpr int EEPROM_SIZE       = 32;
static constexpr int EE_ADDR_CHANNEL   = 0;   // uint8_t
static constexpr int EE_ADDR_TRIM      = 1;   // int8_t
static constexpr int EE_ADDR_BASE_MAC  = 2;   // 6 bytes
static constexpr uint8_t EE_MAGIC      = 0xAB;
static constexpr int EE_ADDR_MAGIC     = 8;
// Lenkungs-Kalibrierung: eigenes Magic, damit eepromClear() (Pairing vergessen)
// sie nicht mitnimmt. 3× uint16 links/mitte/rechts.
static constexpr int EE_ADDR_SERVO_MAGIC = 9;
static constexpr int EE_ADDR_SERVO       = 10;   // 6 bytes
static constexpr uint8_t EE_SERVO_MAGIC  = 0xC5;

// ── Globals ───────────────────────────────────────────────────────────────────
static Adafruit_NeoPixel   gLeds(LED_COUNT, PIN_LED, NEO_GRB + NEO_KHZ800);
static HardwareSerial      gDfSerial(1);
static DFRobotDFPlayerMini gDf;

static void playGameSound(uint8_t track) {
    if (track > 0) gDf.playFolder(FOLDER_GAME, track);
}

static uint8_t  gMyMac[6];
static uint8_t  gBaseMac[6];
static bool     gPaired       = false;
static uint8_t  gSlot         = 0;
static uint8_t  gChannel      = MK_ESPNOW_CHANNEL;
static int8_t   gTrim         = 0;
// Kalibrierte Lenkung (µs), Standard = bisherige feste Grenzen. Links kann auch
// der größere Wert sein, je nach Einbaulage des Servos.
static int16_t  gServoLeft    = SERVO_MIN_US;
static int16_t  gServoCenter  = SERVO_MID_US;
static int16_t  gServoRight   = SERVO_MAX_US;
// Live-Vorschau beim Kalibrieren (aus dem Callback, Loop wertet aus)
static volatile uint16_t gServoPreviewUs = 0;
static volatile uint32_t gServoPreviewMs = 0;
static volatile bool     gServoSavePending = false;
static uint16_t          gServoSaveUs[3];
static uint8_t  gIrId         = 0;       // 0 = IR off
static uint32_t gRumbleUntilMs   = 0;
static uint32_t gLastCollisionMs = 0;
static bool     gImuOk        = false;
static bool     gDfOk         = false;

// Character info
static uint8_t  gCharFolder   = 1;       // DFPlayer folder = character index 1-8
static const char* gCharName  = "?";

// Control state
static int8_t   gThrottle     = 0;
static int8_t   gSteering     = 0;
static uint8_t  gButtons      = 0;
static uint8_t  gPrevButtons  = 0;
static bool     gLightsOn     = false;

// Stern (Grün): Regenbogen auf LED 1–10, solange das Stern-Lied läuft. Die
// Datei ist schon geloopt (4 Durchläufe, 12.4 s) — ein DFPlayer-Neustart pro
// Durchlauf hätte hörbare Lücken. Ende über die Track-Ende-Meldung, STAR_MAX_MS
// als Obergrenze, falls sie verloren geht oder kein DFPlayer da ist. Meldungen
// in den ersten STAR_MIN_MS zählen nicht — die könnten vom vorigen Sound sein.
static constexpr uint32_t STAR_MAX_MS = 20000;
static constexpr uint32_t STAR_MIN_MS = 500;
static bool     gStarActive   = false;
static uint32_t gStarStartMs  = 0;
static volatile uint32_t gLastPacketMs = 0;   // wird im ESP-NOW-Callback gesetzt

// Wie lange ist das letzte Steuerpaket her? Nie direkt "nowMs() - gLastPacketMs"
// rechnen: der Callback läuft in einem eigenen Task und kann gLastPacketMs genau
// zwischen dem nowMs()-Aufruf und dem Lesen neu setzen — dann ist der Wert
// jünger als "jetzt", die Subtraktion läuft unter 0 und ergibt ~4 Mrd. ms.
// Die Neustarts im Leerlauf ("30s nichts von der FB" bei 50 Paketen/s,
// 2026-09-25) kamen allerdings vom Rücksprung der Systemuhr, siehe
// mk_clock_guard.h — seit nowMs() ist das hier nur noch die zweite Absicherung.
static uint32_t msSinceLastPacket() {
    uint32_t last = gLastPacketMs;   // erst den Zeitstempel ...
    uint32_t now  = nowMs();        // ... dann die Uhr
    return (int32_t)(now - last) < 0 ? 0 : now - last;
}
static constexpr uint32_t CONTROL_TIMEOUT_MS = 200;
// Verbindungsverlust auf dem Betriebskanal: das Auto bleibt gepairt und wartet
// auf seine FB — die ist Master und meldet sich auf demselben Kanal mit
// derselben MAC zurück (z.B. nach einem FB-Neustart). Erst nach so langer
// Funkstille gilt die FB als weg und das Auto fällt auf Kanal 1 zurück.
// Absichtlich lang: jeder Rückfall auf Kanal 1 kann die Zuordnung FB↔Auto
// ändern, weil dort die erste FB gewinnt.
static constexpr uint32_t LINK_LOST_MS  = 30000;
static constexpr uint32_t LINK_SHOWN_MS = 1000;   // LED: ab hier "Verbindung weg"
// true = Pairing nach dem Einschalten aus dem EEPROM übernommen, aber noch kein
// Paket gesehen. Dann gilt das kurze PAIR_TIMEOUT_MS statt LINK_LOST_MS.
static bool gRestored = false;

// Pairing state machine
enum class PairState { BEACONING, PAIRED };
static PairState gPairState = PairState::BEACONING;
static uint32_t  gLastBeaconMs   = 0;
static uint32_t  gPairingStartMs = 0;
static constexpr uint32_t BEACON_INTERVAL_MS = 500;
static constexpr uint32_t PAIR_TIMEOUT_MS    = 5000;

// LED state
static uint32_t gLedPhaseMs = 0;
static int8_t   gMappingSlot = 0;  // 0 = normal, 1-8 = show slot color

// Battery state — gBatWired auf true setzen sobald Spannungsteiler verdrahtet
static bool    gBatWired   = true;
static float   gBatVoltage = 8.4f;
static uint8_t gBatLevel   = 5;     // 0–5; 0=kritisch/Cutoff, 5=voll
static bool    gBatCutoff  = false; // true = Abschaltung läuft, nichts mehr ansteuern

// ── EEPROM helpers ────────────────────────────────────────────────────────────
static void eepromLoad() {
    EEPROM.begin(EEPROM_SIZE);
    if (EEPROM.read(EE_ADDR_SERVO_MAGIC) == EE_SERVO_MAGIC) {
        uint16_t v[3];
        EEPROM.get(EE_ADDR_SERVO, v);
        gServoLeft = v[0]; gServoCenter = v[1]; gServoRight = v[2];
        Serial.printf("[SERVO] kalibriert: links %u  mitte %u  rechts %u µs\n", v[0], v[1], v[2]);
    }
    if (EEPROM.read(EE_ADDR_MAGIC) != EE_MAGIC) return;
    gChannel = EEPROM.read(EE_ADDR_CHANNEL);
    gTrim    = (int8_t)EEPROM.read(EE_ADDR_TRIM);
    for (int i = 0; i < 6; i++) gBaseMac[i] = EEPROM.read(EE_ADDR_BASE_MAC + i);
}

static void eepromSaveChannel(uint8_t ch) {
    gChannel = ch;
    EEPROM.write(EE_ADDR_MAGIC, EE_MAGIC);
    EEPROM.write(EE_ADDR_CHANNEL, ch);
    { MkWdtPause wdtPause; EEPROM.commit(); }   // Flash-Schreiben haelt auch die Loop an
}
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
void loop() {
    mkDiagTick();
    mkWatchdogFeed();
    uint32_t now = nowMs();

    if (gOtaRequested) otaHandleRequest();   // kehrt nur bei Ablehnung zurück

    // ── Aktuatoren (immer aus Main-Loop, nie aus Callback) ───────────────────
#ifdef MK_TEST_NO_DRIVE
    // Testbuild (env car_nodrive): Verbindung und alle Pakete laufen normal,
    // aber Motor und Servo bleiben aus — fuer Langzeittests der FB mit
    // abgezogenen Sticks, die sonst Zufallswerte als Fahrbefehle schicken.
    if (true) {
#else
    if (gBatCutoff || !gPaired || msSinceLastPacket() > CONTROL_TIMEOUT_MS) {
#endif
        motorSet(0);
        if (servoPreviewActive()) servoWriteUs(gServoPreviewUs);
        else                      servoSet(0);
        digitalWrite(PIN_LIGHT_REV, LOW);
    } else {
        motorSet(gThrottle);
        // Lenkung kalibrieren: solange Previews kommen, steht der Servo dort,
        // wo die FB ihn haben will (die FB sendet währenddessen Gas 0). Pro
        // Runde genau ein Servowert — nie erst normal, dann Vorschau.
        if (servoPreviewActive()) servoWriteUs(gServoPreviewUs);
        else                      servoSet(gSteering);
        digitalWrite(PIN_LIGHT_REV, gThrottle < 0 ? HIGH : LOW);
    }
    if (gServoSavePending) {
        eepromSaveServo(gServoSaveUs);
        gServoSavePending = false;
    }

    // ── Verbindungsverlust ────────────────────────────────────────────────────
    // Gepairt bleiben und warten, die FB meldet sich auf diesem Kanal zurück.
    // Erst nach LINK_LOST_MS (bzw. PAIR_TIMEOUT_MS direkt nach dem Einschalten
    // ohne ein einziges Paket) zurück auf Kanal 1. Auf Kanal 1 selbst nicht,
    // dort schickt die Basis in der Lobby keine Steuerpakete.
    if (gPaired && gChannel != MK_ESPNOW_CHANNEL) {
        uint32_t limit = gRestored ? PAIR_TIMEOUT_MS : LINK_LOST_MS;
        if (msSinceLastPacket() > limit) {
            Serial.printf("[PAIR] %lus nichts von der FB – reset auf Kanal 1\n",
                          (unsigned long)(limit / 1000));
            eepromClear();
            ESP.restart();
        }
    }

    // ── Pairing beacon ────────────────────────────────────────────────────────
    if (!gPaired) {
        if (now - gLastBeaconMs >= BEACON_INTERVAL_MS)
            sendBeacon();

        charPoll(now);

        // Kein Pairing nach 5s auf gespeichertem Kanal → EEPROM löschen, Neustart auf CH1
        if (!gPaired && gChannel != MK_ESPNOW_CHANNEL &&
            now - gPairingStartMs >= PAIR_TIMEOUT_MS) {
            // Gnadenfrist: der ESP-NOW-Callback läuft in einem eigenen Task und
            // kann gPaired/gChannel genau jetzt noch setzen (Assign+ChannelSwitch
            // treffen erfahrungsgemäß nah an der 5s-Marke ein). Kurz warten und
            // erneut prüfen, bevor EEPROM unwiderruflich gelöscht wird — sonst
            // sabotiert der Timeout ein Pairing, das im selben Moment fertig wird.
            MkWdtPause wdtPause;
            delay(100);
            if (!gPaired) {
                Serial.println("[PAIR] Timeout – reset auf Kanal 1");
                eepromClear();
                ESP.restart();
            }
        }
    }

    // ── DFPlayer-Rückmeldungen ausgeben (Diagnose) ───────────────────────────
    if (gDfOk && gDf.available()) {
        uint8_t t = gDf.readType();
        int     v = gDf.read();
        // Track-Ende: Original meldet PlayFinished (0x3D), die verbauten
        // Nachbau-Module stattdessen eine Rückmeldung mit Kommando 0x4C.
        bool finished = (t == DFPlayerPlayFinished) ||
                        (t == DFPlayerFeedBack && gDf.readCommand() == 0x4C);
        if (finished && gStarActive && now - gStarStartMs >= STAR_MIN_MS) {
            gStarActive = false;
            Serial.println("[STAR] Ende (Lied fertig)");
        }
        if (t == DFPlayerError) {
            const char* why = (v == FileMismatch) ? "Datei nicht gefunden (Ordner/Dateiname?)"
                            : (v == FileIndexOut) ? "Track-Index ausserhalb"
                            : (v == Busy)         ? "Modul busy / keine Karte"
                            : (v == Advertise)    ? "Advertise-Fehler"
                            : "unbekannt";
            Serial.printf("[DF] FEHLER %d — %s\n", v, why);
        } else if (t == DFPlayerPlayFinished) {
            Serial.printf("[DF] Track %d fertig\n", v);
        } else {
            Serial.printf("[DF] type=%d cmd=0x%02X value=%d\n", t, gDf.readCommand(), v);
        }
    }

    // ── Button-Log: jede Änderung der Tastenmaske von der FB ─────────────────
    static uint8_t lastLoggedButtons = 0;
    if (gButtons != lastLoggedButtons) {
        if (gButtons) {
            Serial.printf("[BTN] 0x%02X %s%s%s%s\n", gButtons,
                          (gButtons & MK_BTN_YELLOW) ? "YELLOW " : "",
                          (gButtons & MK_BTN_GREEN)  ? "GREEN "  : "",
                          (gButtons & MK_BTN_BLUE)   ? "BLUE "   : "",
                          (gButtons & MK_BTN_RED)    ? "RED "    : "");
        } else {
            Serial.println("[BTN] 0x00 — alle los");
        }
        lastLoggedButtons = gButtons;
    }

    if (gStarActive && now - gStarStartMs >= STAR_MAX_MS) {
        gStarActive = false;
        if (gDfOk) gDf.stop();
        Serial.println("[STAR] Ende (Zeitlimit)");
    }
    lightsUpdate(now);

    // ── Buttons: Blue → Joy-Sound, Red → Licht, Green → Stern ────────────────
    if (gPaired) {
        bool blueNow  = (gButtons     & MK_BTN_BLUE) != 0;
        bool bluePrev = (gPrevButtons & MK_BTN_BLUE) != 0;
        // Während des Sterns kein Joy-Sound — er würde das Stern-Lied abbrechen.
        if (gDfOk && blueNow && !bluePrev && !gStarActive) {
            const CharSounds& s = kSounds[gCharFolder - 1];
            if (s.joyCount > 0) {
                uint8_t track = s.joy[esp_random() % s.joyCount];
                Serial.printf("[SND] playFolder(%d, %d) → /%02d/%03d.mp3\n",
                              gCharFolder, track, gCharFolder, track);
                gDf.playFolder(gCharFolder, track);
            }
        }

        bool redNow  = (gButtons     & MK_BTN_RED) != 0;
        bool redPrev = (gPrevButtons & MK_BTN_RED) != 0;
        if (redNow && !redPrev) {
            gLightsOn = !gLightsOn;   // lightsUpdate() setzt es um
        }

        bool greenNow  = (gButtons     & MK_BTN_GREEN) != 0;
        bool greenPrev = (gPrevButtons & MK_BTN_GREEN) != 0;
        if (greenNow && !greenPrev && !gStarActive) {
            if (gDfOk) playGameSound(SND_STAR);
            gStarActive  = true;
            gStarStartMs = now;
            Serial.println("[STAR] Start");
        }

        gPrevButtons = gButtons;
    }

    // ── Collision check (10Hz) ────────────────────────────────────────────────
    static uint32_t lastImu = 0;
    if (now - lastImu >= 100) {
        checkCollision();
        lastImu = now;
    }

    // ── Feedback to base (5Hz) ────────────────────────────────────────────────
    static uint32_t lastFb = 0;
    if (gPaired && (now - lastFb >= 200)) {
        MK_GameFeedback fb{};
        fb.carBat  = readBattery();
        fb.rumble  = (nowMs() < gRumbleUntilMs) ? 1 : 0;
        fb.trim    = gTrim;
        espnowSend(gBaseMac, &fb, sizeof(fb));
        lastFb = now;
    }

    // ── Battery update (1Hz) ─────────────────────────────────────────────────
    static uint32_t lastBat = 0;
    if (now - lastBat >= 1000) {
        batUpdate();
        lastBat = now;
    }

    // ── LED update (50Hz) ─────────────────────────────────────────────────────
    static uint32_t lastLed = 0;
    if (now - lastLed >= 20) {
        ledUpdate();
        lastLed = now;
    }
}

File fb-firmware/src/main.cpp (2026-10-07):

#include <Arduino.h>
#include <Wire.h>
#include <EEPROM.h>
#include <Adafruit_ADS1X15.h>
#include <Adafruit_ST7789.h>
#include <SPI.h>
#include <Adafruit_NeoPixel.h>
#include <WiFi.h>
#include <esp_now.h>
#include <esp_wifi.h>
#include <esp_sleep.h>
#include <driver/gpio.h>
#include "mk_protocol.h"
#include "mk_clock_guard.h"
#include "mk_watchdog.h"

// --- Pins (ESP32-C6-SuperMini, Repin 2026-09-06) ---
// Tabu: GPIO12/13 (USB D-/D+), GPIO8/9 (RGB-LED / BOOT-Strap),
//       GPIO16/17 (UART0 — TXD0 wird vom Boot-ROM aktiv getrieben; auf V2
//       traegt GPIO16 bewusst die Status-LED, ein reiner Ausgang).
// ADC1 liegt nur auf GPIO0–6, der Batterie-Monitor muss dorthin.
#define PIN_BAT_ADC      0   // ADC1_0, externer Teiler 100k/100k
#define PIN_MODE         1   // fest an 3.3V/GND — darf kein UART0-TX sein
#define PIN_BTN_RED      2
#define PIN_BTN_BLUE     3
#define PIN_BTN_GREEN    4
// FB-Board V2 (2026-10-06): Gelb von inneren Pad 23 an die Hauptleiste
// (GPIO5), Display-MOSI auf GPIO6, Status-LED auf GPIO16 (UART0 TX — der
// Boot-ROM gibt dort ~17 ms sein Startprotokoll aus, die LED blitzt beim
// Einschalten evtl. kurz in einer Zufallsfarbe, bis setup() sie setzt).
// Kein fliegender Draht mehr. env fb_v2 setzt -DFB_REV=2.
#ifndef FB_REV
#define FB_REV 1
#endif
#if FB_REV == 2
#define PIN_TFT_MOSI     6   // Display SDA, ueber R17 33 Ohm
#define PIN_LED         16   // WS2812B DATA, ueber R6 330 Ohm
#else
#define PIN_TFT_MOSI     5   // FSPI MOSI — IO_MUX, volle Taktrate
#define PIN_LED          6   // WS2812B DATA
#endif
#define PIN_TFT_SCK      7   // FSPI SCK — IO_MUX, volle Taktrate
#define PIN_TFT_BL      14   // Backlight, PWM-gedimmt
#define PIN_TFT_CS      15
// GPIO16 = UART0 TXD0 — im Layout nicht erreichbar, bleibt frei.
#define PIN_RUMBLE      17   // LEDC. GPIO17 = UART0 RXD0 — der ROM liest den Pin
                             // nur, treibt ihn nie. Kein Motorzappeln beim Boot.
#define PIN_TFT_DC      18
#define PIN_I2C_SDA     19
#define PIN_I2C_SCL     20
// GPIO21-23 liegen auf den inneren Pads des SuperMini, nicht an den
// Hauptleisten — dort ist je ein Draht noetig.
#define PIN_BTN_STICK_R 21   // reserviert, bewusst ohne Funktion
#define PIN_BTN_STICK_L 22   // reserviert, bewusst ohne Funktion
#if FB_REV == 2
#define PIN_BTN_YELLOW   5   // Hauptleiste. Strap MTDI (nur SDIO-Flanke) → folgenlos
#else
#define PIN_BTN_YELLOW  23   // inneres Pad — einziger Draht. Bewusst ein Taster
                             // und nicht MOSI: bei einem Tastersignal ist eine
                             // fliegende Verbindung unkritisch.
#endif

// --- ADS1115 Kanäle ---
// ADS1115-Kanal je Achse, am Gerät gemessen (2026-10-04, Log der Rohwerte).
// Die Belegung laut Schaltplan (A0 = links X ... A3 = rechts X) stimmte nicht
// mit der Einbaulage der Sticks überein. Alles Weitere folgt diesen vier
// Zeilen — Fahren, Menü-Navigation und auch CAL_STEP_CH.
#define JS_LEFT_X   2   // linker Stick seitlich
#define JS_LEFT_Y   3   // linker Stick vor/zurück
#define JS_RIGHT_Y  0   // rechter Stick vor/zurück
#define JS_RIGHT_X  1   // rechter Stick seitlich
// Kanäle, deren Rohwert entgegen der Erwartung läuft (rechts = kleiner Wert) —
// bei beiden Sticks die Seitwärtsachse. Gilt für Fahrbefehl und
// Menü-Navigation, nicht für die Kalibrierung.
#define JS_INVERTED(ch)  ((ch) == JS_RIGHT_X || (ch) == JS_LEFT_X)

// --- Display: 1.9" IPS 170x320 ST7789, Querformat ---
// init(170,320) laesst die Library colstart=35 / rowstart=0 rechnen — genau der
// Versatz, mit dem das 170er-Panel im 240x320-Controller sitzt.
// setRotation(1) dreht auf Querformat. Steht das Bild auf dem Kopf: 3 statt 1.
#define TFT_PANEL_W  170
#define TFT_PANEL_H  320
#define TFT_ROTATION   1
#define TFT_W        320
#define TFT_H        170

// GFX-Standardfont: 6x8 bei Groesse 1, also 12x16 bei Groesse 2.
// Groesse 2 ist die Basis — 26 Zeichen pro Zeile, 10 Zeilen.
#define CH_W          12
#define CH_H          16
#define TITLE_Y        6
#define RULE_Y        28
#define BODY_Y        40
#define LINE_H        22

// Backlight per LEDC gedimmt statt hart auf HIGH: spart Strom (das 1.9"-IPS
// zieht bei voller Helligkeit 30–60mA) und spaeter 18650-Laufzeit.
#define TFT_BL_FREQ   5000
#define TFT_BL_RES       8
#define TFT_BL_LEVEL   150   // ~60%, drinnen gut ablesbar
#define TFT_BL_DIM      10   // ~4%, nach TFT_DIM_AFTER_MS ohne Eingabe
#define TFT_DIM_AFTER_MS 60000

// Farben (RGB565)
#define COL_BG       ST77XX_BLACK
#define COL_FG       ST77XX_WHITE
#define COL_DIM      0x8410
#define COL_ACCENT   0xFD20
#define COL_OK       0x07E0
#define COL_WARN     0xFFE0
#define COL_CRIT     0xF800

// --- Rumble ---
// Auf dem C6 ist PWM Hardware (LEDC). Das Brummen beim Verbindungsverlust auf
// dem ESP8266 kam von dessen Software-PWM, die unter WLAN-Interruptlast glitchte
// — diese Fehlerklasse entfaellt hier.
#define RUMBLE_PWM          255
#define RUMBLE_PWM_FREQ   20000
#define RUMBLE_PWM_RES        8

// --- Timings ---
#define LOOP_PERIOD_MS    20     // 50 Hz Zielfrequenz
#define DISPLAY_PERIOD_MS 100   // Mindestabstand zwischen Display-Updates (Normalscreen, Teil-Updates)
#define CAL_HOLD_MS   3000
#define CAL_PULSE_MS  3000
#define CAL_SHOW_MS   3000

// --- Joystick ---
// Spannungsteiler: R_top = R_bot (beliebiger gleicher Wert 1k–100k)
// → V_out = 5V × 0.5 = 2.5V, ADS-Wert = 2.5/4.096 × 32767 ≈ 19989
// Minimum: Joystick bei GND → 0V → ADS ≈ 0
// Default-Center: halber Bereich (überschrieben durch die Offset-Kalibrierung im Menü, EEPROM)
#define JS_DEFAULT_MIN     0
#define JS_DEFAULT_MAX     19989
#define JS_DEFAULT_CENTER  9994      // JS_DEFAULT_MAX / 2
#define JS_MENU_THRESHOLD  4500      // ~45% Auslenkung ab Center für Menünavigation
#define JS_MENU_HIGH       (JS_DEFAULT_CENTER + JS_MENU_THRESHOLD)   // ≈ 14494
#define JS_MENU_LOW        (JS_DEFAULT_CENTER - JS_MENU_THRESHOLD)   // ≈ 5494
#define JS_DEADZONE        6
#define MENU_COOLDOWN      300
#define ADC_OVERSAMPLE     4    // Samples pro Kanal im Normalbetrieb (STATE_READY)

// --- EEPROM ---
#define EEPROM_MAGIC        0xCAFE
#define EEPROM_ADDR_MAGIC   0
#define EEPROM_ADDR_CENTER  2   // 4x int16 = 8B
#define EEPROM_ADDR_MIN    10   // 4x int16 = 8B
#define EEPROM_ADDR_MAX    18   // 4x int16 = 8B
#define EEPROM_ADDR_TRIM    26   // int8 — unbenutzt, der Trim gehoert dem Auto
#define EEPROM_ADDR_LANG    27   // uint8
#define EEPROM_ADDR_CHANNEL 28   // uint8, 0 = kein gespeicherter Kanal
#define EEPROM_ADDR_CARMAC  29   // 6B, MAC des zuletzt gepairten Autos (Direct Mode)
#define EEPROM_SIZE         40

// --- Trim & Speed ---
#define TRIM_STEPS  21
#define TRIM_MIN   -10
#define TRIM_MAX    10
#define SPEED_STEPS  10
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

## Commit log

2026-05-16 FB-Firmware: Display, WS2812B, Kalibrierung, EEPROM
    - Display: Live-Joystick/Button-Daten oben, Serial-Eingabebereich unten
    - Joystick-Mapping auf -100..100 mit per-Achse Kalibrierung
    - Kalibrierung: Boot-automatisch + manuell via B1+B2 (3s halten)
    - EEPROM: Kalibrierungswerte bleiben über Neustarts erhalten
    - WS2812B auf D4: Grün=bereit, Gelb pulsierend=Cal-Trigger, Gelb=kalibriert
    - Rumble auf D8 (war D4/GPIO2 – UART1-Interferenz behoben)
    - Button 4 auf D3 (war D8/GPIO15 – Pull-Down-Problem behoben)
    - Rumble-Motor auf 5V umgestellt (3.3V zu schwach)
    - .gitignore: .pio/ ausgeschlossen
    - README: vollständig aktualisiert mit finalem Pinout und Projektstand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
    [main.cpp]
2026-05-17 Docs & Firmware: Modi, LED-States, Kalibrierung, Dead Zone
    FB-Firmware:
    - Kalibrierungs-Combo auf B2+B3 geändert
    - Dead Zone ±5 auf Joystick-Mapping
    - Serial zeigt Rohwerte, Display gemappte Werte
    Dokumentation (CLAUDE.md + README):
    - Finales Pinout: D0=Modus, D3=B4, D4=WS2812B, D8=Rumble
    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
2026-05-17 FB-Firmware: Einstellungsmenü, Race-Display-Layout, Peripherie-Guards
    - Einstellungsmenü (B2+B3 3s): Offset-Kalibrierung, Min/Max-Kalibrierung
    (8 Schritte geführt), Servo-Trim, Max. Speed, Sprache (DE/EN)
    - Asymmetrisches Joystick-Mapping mit EEPROM-persistenten Min/Max-Werten
    - Peripherie-Guards: bootet ohne ADS1115/SSD1306 ohne Crash
    - Zyklisches Rumble deaktiviert
    - Race-Display-Layout definiert (Sprite, Position, Runde, Item-Icon)
    - CLAUDE.md + README: Firmware-Stand, Display-Plan (2.42" SSD1309),
    Race-Display, OTA geparkt, verworfene Optionen ergänzt
    [main.cpp]
2026-05-17 Fix: Einstellungsmenü öffnet korrekt + Doku-Update
    - STATE_READY→STATE_MENU: return false verhindert displayNormal()-Überschreiben
    - README: Display (2.42" SSD1309) als bestellt markiert, Bugfix-Eintrag
    [main.cpp]
2026-05-18 FB-Firmware: Protokoll, Button-Farben, Joystick-Mapping, Refactoring
    - shared/mk_protocol.h: ESP-NOW Datenstrukturen definiert (MK_ControlInput,
    MK_ConfigPacket, MK_GameFeedback) mit Typ-Discriminator
    - platformio.ini: -I../shared für shared/ Header eingebunden
    - Buttons: B1-B4 → SNES-Farbnamen (Yellow/Green/Blue/Red), TBD beim PCB-Layout
    Edge-Detection für alle vier Buttons (bYellowP, bGreenP, bBlueP, bRedP)
    - Menü: Green+Blue Combo, Yellow=bestätigen, Red=zurück
    Neue Einträge: Rumble-Toggle, Joysticks tauschen (Session), Reset
    - Joystick-Mapping: throttle/steering statt roher Achswerte,
    Swap-Option (LY↔RY / RX↔LX) als Session-Toggle
    - JS-Defaults: Magic Numbers durch De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
    [main.cpp, mk_protocol.h]
2026-05-18 Protocol: Beacon/Assign, Channel-Switch, DEADBEEF Base MAC
    - MSG_BEACON/ASSIGN: device registration flow, mode-agnostic pairing
    Direct Mode: FB temporarily spoofs DEADBEEF:BA5E, assigns itself as target
    Game Mode: real base station at DEADBEEF:BA5E handles assignment
    - MSG_CHANNEL_SWITCH: base station broadcasts optimal channel after scan
    Devices register on MK_ESPNOW_CHANNEL (1), switch before race start
    - MK_BASE_MAC: DE:AD:BE:EF:BA:5E — spoofed by base gateway and FB in Direct Mode
    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
2026-05-18 FB-Firmware: ESP-NOW Implementierung + LED/Display-Bereinigung
    ESP-NOW:
    - initEspNow(): WiFi STA, MAC-Spoof (Direct: DEADBEEF:BA5E), Kanal, Callback
    - onDataRecv(): empfängt MK_Beacon (Direct) und MK_Assign (Game), setzt Flags
    - handlePairing(): verarbeitet Flags, registriert Peer, sendet MK_Assign (Direct),
    stellt eigene MAC wieder her
    - sendBeacon(): Game Mode, 500ms Intervall, Unicast an MK_BASE_MAC (kein Broadcast)
    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
2026-05-18 Direct Mode: zufälliger Kanalwechsel nach Pairing
    FB wählt nach erfolgreichem Pairing zufällig aus {1, 6, 11} (nicht-überlappende
    2.4-GHz-Kanäle) und fordert das Auto per MK_ChannelSwitch zum Wechsel auf.
    Verteilt mehrere Direct-Mode-Paare auf verschiedene Kanäle und reduziert
    Interferenz ohne aufwändigen Kanal-Scan.
    Game Mode bleibt unverändert: Basis-Station übernimmt Kanalwahl via RPi-Trigger.
    MK_DIRECT_CHANNELS / MK_DIRECT_CHAN_COUNT in mk_protocol.h dokumentiert.
    [main.cpp, mk_protocol.h]
2026-05-18 Protocol & FB-Firmware: Feedback-Empfang, Kanal-Persistenz, Loop-Timing, Display-Optimierung
    mk_protocol.h:
    - MK_GameFeedback-Empfang definiert (rumble 0/1, speedLimit)
    - Kanal-Lebenszyklus dokumentiert (Boot, Rennstart, Rennende via MSG_CHANNEL_SWITCH)
    - Reconnect-Vertrag: EEPROM-Kanal für FB und Auto, 5s-Timeout + Reboot
    - Car-Firmware-Vertrag: Re-Beacon auf aktuellem Kanal nach Control-Timeout
    - MSG_MAPPING + MK_MAPPING_COLORS (8 Farben für Mapping-Prozess)
    - MK_BTN_YELLOW/GREEN/BLUE/RED Bitmasken
    - Control-Timeout-Pflicht für Empfänger dokumentiert
    fb-firmware/src/main.cpp:
    - MK_GameFeedback-Empfang: noInterrupts-sicherer Copy, rumble on/off, speedLimit-Cap
    - MSG_CHANNEL_SWITCH post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
    [main.cpp, mk_protocol.h]
2026-05-18 Protocol & FB-Firmware: Akku-Icon Auto (carBat 0–5), Build-Fixes
    - MK_GameFeedback: uint8_t carBat hinzugefügt (0=leer…5=voll, vorquantisiert
    vom Fahrzeug — verhindert Display-Jitter durch LiPo-Spannungsrauschen)
    - FeedbackState: carBat-Feld, onDataRecv + handleFeedback kopieren es
    - displayNormal: zweites Akku-Icon (95,1) für Fahrzeug neben FB-Icon (113,1)
    - drawBatteryIcon refaktoriert → drawBatteryIconBars(bars, x, y) als Basis
    - Build-Fix: FeedbackState + paired/trySavedChannel/feedback in Globals-Block
    verschoben (waren nach displayNormal deklariert → Forward-Reference-Fehler)
    - Build-Fix: onDataRecv Callback-Signatur uint8_t len (war int)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
    [main.cpp, mk_protocol.h]
2026-05-18 FB-Firmware: ESP-NOW Globals in eigenen Block hochgezogen
    Alle ESP-NOW Variablen und Defines aus dem Implementierungsbereich
    in einen dedizierten "ESP-NOW Globals" Block am Dateianfang verschoben.
2026-05-18 Protocol & FB-Firmware: MK_ConfigPacket (Trim) senden
    - mk_protocol.h: Kommentar ergänzt — Basis MUSS MK_ConfigPacket unicast
    ans Auto weiterleiten (wird von der Basis nicht selbst ausgewertet)
    - sendConfigPacket(): sendet Trim-Wert per ESP-NOW an peerMac
    - Trim-Menü: sendConfigPacket() wird beim Bestätigen (Gelb) aufgerufen
2026-05-18 Protocol & FB-Firmware: MSG_MAPPING empfangen + anzeigen
    - mk_protocol.h: MK_Mapping.slot → int8_t; slot=-1 beendet Mapping.
    Dokumentiert: Basis sendet -1 an alle FBs wenn Mapping abgeschlossen.
    - mappingSlot (volatile int8_t): Global für ISR-sicheren Transfer
    - onDataRecv: MSG_MAPPING-Case ergänzt
    - displayMapping(): zeigt Slot-Nummer groß auf Display
    - Loop: Mapping-Display hat Vorrang vor Normal-Display solange slot >= 1
2026-05-19 Docs: README auf aktuellen Stand gebracht
    - Protokoll-Tabelle: alle 7 Msg-Typen (Beacon, Assign, ChannelSwitch, Mapping)
    - MK_GameFeedback: carBat ergänzt; MK_Mapping -1-Semantik dokumentiert
    - MK_ConfigPacket: Basis-Weiterleitungspflicht erwähnt
    - LED-Tabelle: korrigiert (kein Blau, Pink für Menü, Akku-Zustände)
    - Projektstatus: ESP-NOW, Loop-Timing, Pairing, Feedback, Mapping als ✅
2026-05-19 FB-Firmware: feature-complete + Docs aktualisiert
    - Scrollendes Menü (9 Einträge, 6 sichtbar, Scrollbar)
    - Debug-Ansicht: Achsen, Buttons, Spannung, Kanal, MAC
    - Rumble: 2× ERM-Motor 28×12mm direkt an LiPo VCC, nur ESP-NOW ausgelöst
    - LED: grün nur wenn paired, orange pulsierend beim Suchen
    - speedLimit aus MK_GameFeedback + FB-Firmware entfernt (Basis wendet Limits direkt am Auto an)
    - CLAUDE.md + README.md auf aktuellen Stand gebracht
2026-05-24 Auto-Firmware: feature-complete + Direct Mode End-to-End getestet
    - car-firmware/src/main.cpp: vollständige Fahrzeug-Firmware
    ESP-NOW Pairing/Reconnect, Motor (BTS7960), Servo (1050-1950µs),
    WS2812B (8 Char-LEDs + 1 Status), DFPlayer (GPIO20/21, joy/sad-Arrays),
    LSM6DS3 Kollisionserkennung (±16g, 6g-Threshold, 2s Rumble),
    EEPROM (Channel, Trim, BaseMac), IR-Gating via MSG_IR_CONFIG
    - shared/mk_protocol.h: MSG_IR_CONFIG (0x14) + MK_IrConfig hinzugefügt,
    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
2026-07-18 Auto-Firmware: ESP32-C6 Repin, Servo/Motor-Kanalkonflikt behoben, Batterie-ADC ergänzt
    Board auf ESP32-C6 Mini umgestellt und Pins neu belegt (DFPlayer-UART weg von
    GPIO8/9 auf 14/15, da Boot-Strapping-Pins sonst in Download-Modus booten).
    Servo wird jetzt vor dem Motor attached, damit ESP32Servo und die rohen
    ledcAttach()-Aufrufe nicht um LEDC-Kanal 0 kollidieren (Ursache für
    Servo-Ausfall + Motor-Rauschen). Batterie-Spannungsteiler-Monitoring
    implementiert, onRecv auf neue esp_now-API angepasst, Base-Station-Protokoll
    (Multi-S3-Relay) in mk_protocol.h ergänzt.
    [main.cpp, mk_protocol.h]
2026-07-18 Auto-Firmware: Servo-Attach-Check korrigiert (Rückgabewert war Kanalnummer)
    Servo::attach() gibt die LEDC-Kanalnummer zurück, nicht Erfolg/Misserfolg —
    Kanal 0 ist in C++ falsy, daher meldete der bisherige if-Check bei
    erfolgreichem Attach auf Kanal 0 fälschlich "[SERVO] FEHLER". Jetzt wird
    stattdessen gServo.attached() geprüft.
    [main.cpp]
2026-09-18 Footprint 2P3T-Schalter: GND-Laschen-Langloecher vergroessert
    Die Loetlaschen des verbauten Schalters passten auf dem gelieferten
    Board nicht in die Langloecher (1.0 x 0.6mm, nur 0.15mm Luft pro Ende
    gegenueber der vermessenen Lasche von 0.7 x 0.3mm).
    - Bohrung 1.0 -> 2.2mm Laenge, Breite 0.6mm unveraendert
    - aeussere Lochkante 0.2mm nach aussen (7.80 -> 8.00mm), der restliche
    Zuwachs geht nach innen -> Lochzentrum 7.3 -> 6.9mm
    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
2026-09-25 FB auf ESP32-C6 portiert, Reconnect FB-gesteuert, C6-SYSTIMER-Fix
    Fernbedienung
    - Port D1 Mini/ESP8266 → ESP32-C6-SuperMini (ESP-NOW, LEDC, ST7789, OTA-Partitionen)
    - Menue: Bestaetigen mit Gruen statt Gelb
    - Display: Teil-Updates statt fillScreen (kein Schwarzblitzen), Achsen live,
    Abdunkeln nach 60 s ohne Eingabe
    - USB-CDC: TX-Timeout 0, Loop blockiert nicht mehr ohne offenen Monitor
    - Trim gehoert dem Auto: FB liest ihn aus dem Feedback, Live-Vorschau im Menue
    - Akku-Messung aktiv, 0% = 3.4V, Tiefentladeschutz: <3.3V fuer 30 s → Deep Sleep
    Auto
    - Licht auf Rot statt Gelb
    - Pairing aus EEPROM wiederherstellen, 30 s Rueckfall auf Kanal 1, Trim bleibt erhalten
    - Servo direkt ueber LED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
    [main.cpp, mk_protocol.h]
2026-09-25 KiCad-Projekte: Kart- und FB-Board, eigene Symbole/Footprints, Gerber
    - docs/kart: kart.* (Fahrzeug) und controller.* (Fernbedienung) mit
    Schaltplan, Layout und Projektdatei
    - Eigene Bibliotheken zzzz_Own (Symbole + .pretty-Footprints) und
    RF_Module_Own, Bibliothekstabellen
    - Gerber als ZIP fuer die Fertigung
    - .gitignore fuer KiCad-Locks, Sicherungen, .history und *.kicad_prl
    [Kicad.kicad_pcb, Kicad.kicad_sch, controller.kicad_pcb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]
2026-09-25 README auf aktuellen Stand gebracht
    Stand vorher: 24.05. (D1 Mini, ESP32-C3, OLED, alte Pinbelegung). Jetzt:
    ESP32-C6 in FB und Auto, aktuelle Hardware und Pinbelegung, Tastenbelegung,
    FB-gesteuertes Wiederverbinden, Tiefentladeschutz, C6-rev-v0.2-Uhrenfehler,
    Projektstatus und verworfene Optionen.
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2026-10-07 Repo für Veröffentlichung vorbereitet: KiCad-Struktur, Lizenz, Aufräumen
    - KiCad-Projekte je Platine nach kicad/projects/<board>/ (kart, controller,
    buttons, switch), eigene Bibliotheken nach kicad/libs/, projektlokale
    sym-lib-table/fp-lib-table auf ${KIPRJMOD}/../../libs
    - Schalter-Platinchen: einschalter -> switch, Titelblock vereinheitlicht
    - AO4407A: 3D-Modell auf KiCad-Standard-SOIC-8, Footprint-Verweis korrigiert
    - Alte Stände nach kicad/archive/ (FB-V1-Layout, D1-Mini-Schaltplan)
    - Lizenz CC BY-NC-SA 4.0, Fan-Projekt-Hinweis
    - CLAUDE.md nicht mehr versioniert, PDFs/DOCX/Exporte ignoriert
    - Laufende Firmware-Änderungen (Kart V2, FB V2, Stern-Licht) mitcommittet
    - docs/wiki-pla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
    [buttons.kicad_pcb, buttons.kicad_sch, controller.kicad_pcb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]
2026-10-07 AO4407A: 3D-Modell um -90° gedreht, Beinchen und Pin 1 passen zu den Pads
    [switch.kicad_pcb]
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2026-10-07 FB: veralteten Kommentar zur Offset-Kalibrierung korrigiert; Wiki-Plan Schritt 8 abgeschlossen
    [main.cpp]
2026-10-07 Kart: Erkennungssound beim Kaltstart wieder hörbar
    Der DFPlayer wurde erst nach den Servo-/Motortests per begin() zurückgesetzt,
    Lautstärke und Play-Befehl direkt danach gingen verloren (die 200-ms-Pause
    davor gab es nur noch mit DF_DIAG). Jetzt: Reset vor den Selbsttests,
    Lautstärke und Erkennungssound danach — der DFPlayer hat ~1.4 s zum Hochfahren.
    [main.cpp]
2026-10-07 Stücklisten als CSV (docs/bom), Export im Skript; Wiki-Plan Schritt 11
    [buttons.csv, controller.csv, kart.csv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]
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
